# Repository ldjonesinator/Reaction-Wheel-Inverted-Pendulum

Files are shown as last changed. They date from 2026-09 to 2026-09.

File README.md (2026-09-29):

# Reaction Wheel Inverted Pendulum
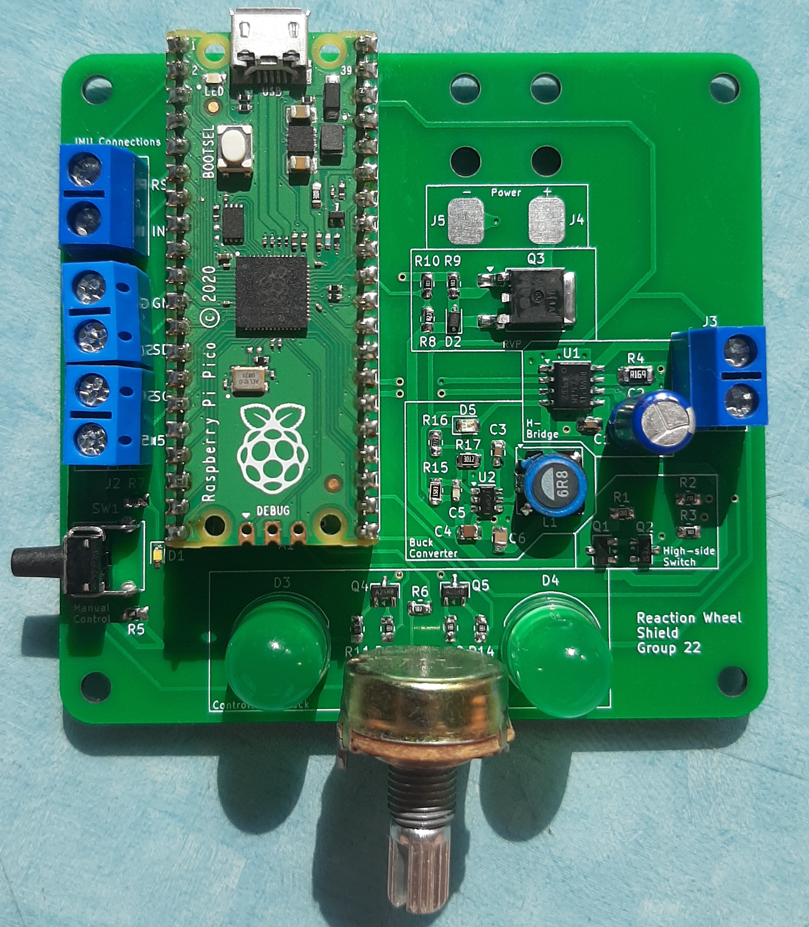
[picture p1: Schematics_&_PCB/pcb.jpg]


## How it works
An inverted pendulum is an inherently unstable mechanical system because its centre of mass is positioned above its pivot point. As a result, small disturbances cause the pendulum to move away from its upright position unless corrected back to its original position. In this project, torque is produced by accelerating or decelerating a reaction wheel mounted to the pendulum. The resulting reaction torque acts on the pendulum body and is used to oppose its movement. 

The design uses an inertial measurement unit (IMU), to measure the pendulum’s angular position and motion. These measurements are processed by a Raspberry Pi Pico, which runs the feedback-control algorithm. The resulting control signal is supplied to an H-bridge motor driver, allowing the speed and direction of the brushed geared DC motor to be controlled. The motor drives the reaction wheel, completing the closed-loop control system. 

## How to use
You can refer to the documentation located in: [Instructions](Instructions.pdf)

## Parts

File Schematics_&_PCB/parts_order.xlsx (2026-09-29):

Component | Link | Part number | Amount | Price (NZD) | Total Price
Buck Switching Regulator IC Positive Adjustable AP63301WU-7 | https://www.digikey.co.nz/en/products/detail/diodes-incorporated/AP63301WU-7/10491607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 | 31-AP63301WU-7CT-ND | 1 | $1.99 | $1.99
H-Bridge DRV8231DDAR | https://www.digikey.co.nz/en/products/detail/texas-instruments/DRV8231DDAR/16184249 | 296-DRV8231DDARCT-ND | 1 | $3.24 | $3.24
Red Banana socket | https://www.digikey.co.nz/en/products/detail/cliff-electronic-components-ltd/FCR7350R/17729035 | 4654-FCR7350R-ND | 0 | $14.04 | $0.00
Black Banana socket | https://www.digikey.co.nz/en/products/detail/cliff-electronic-components-ltd/FCR7350B/17729030 | 4654-FCR7350B-ND | 0 | $14.04 | $0.00
Cyan 2P Screw Terminal TB002-500-02BE | https://www.digikey.co.nz/en/products/detail/same-sky-formerly-cui-devices/TB002-500-02BE/10064069 | 102-6145-ND | 1 | $0.70 | $0.70
Green 2P Screw Terminal 691137710002 | https://www.digikey.co.nz/en/products/detail/w%C3%BCrth-elektronik/691137710002/6644051 | 732-10955-ND | 1 | $0.79 | $0.79
Green 4P Screw Terminal 691137710004 | https://www.digikey.co.nz/en/products/detail/w%C3%BCrth-elektronik/691137710004/6644053 | 732-10957-ND | 1 | $1.52 | $1.52
Green 10mm LED WP813GD | https://www.digikey.co.nz/en/products/detail/kingbright/WP813GD/3084264 | 754-1898-ND | 2 | $0.69 | $1.38
Right angle THT Switch 1-1825027-1 | https://www.digikey.co.nz/en/products/detail/te-connectivity-alcoswitch-switches/1-1825027-1/1632544 | 450-1658-ND | 1 | $0.56 | $0.56
Orange LED 2mA XZCM2MOK54WA-1VF | https://www.digikey.co.nz/en/products/detail/sunled/XZCM2MOK54WA-1VF/15761908 | 1497-XZCM2MOK54WA-1VFCT-ND | 1 | $0.98 | $0.98
White LED 5mA LW Q98G.01-R2T1-3K6L-1-5-R18 | https://www.digikey.co.nz/en/products/detail/ams-osram-ag/LW-Q98G-01-R2T1-3K6L-1-5-R18/21556497 | 475-LWQ98G.01-R2T1-3K6L-1CT-ND | 1 | $0.36 | $0.36
20p Female Connector 61302011821 | https://www.digikey.co.nz/en/products/detail/w%C3%BCrth-elektronik/61302011821/16608603 | 732-61302011821-ND | 2 | $1.83 | $3.66
PMOS 100V 6.6A FQD8P10TM | https://www.digikey.co.nz/en/products/detail/onsemi/FQD8P10TM/1054070 | FQD8P10TMCT-ND | 1 | $2.78 | $2.78
PMOS 30V 4.3A DMP3056L-7 | https://www.digikey.co.nz/en/products/detail/diodes-incorporated/DMP3056L-7/5126843 | DMP3056L-7DICT-ND | 1 | $1.31 | $1.31
NMOS 60 V 265mA NX138BKR | https://www.digikey.co.nz/en/products/detail/nexperia-usa-inc/NX138BKR/5981270 | 1727-2662-1-ND | 1 | $0.36 | $0.36
NMOS 20 V 3A SLMT320V3CN | https://www.digikey.co.nz/en/products/detail/shenzhen-slkormicro-semicon-co-ltd/SLMT320V3CN/29782446 | 5399-SLMT320V3CNCT-ND | 2 | $0.21 | $0.41
DIODE ZENER 24V 300mW MM3Z24VT1G | https://www.digikey.co.nz/en/products/detail/onsemi/MM3Z24VT1G/661665 | MM3Z24VT1GOSCT-ND | 1 | $0.33 | $0.33
47uF Al Electrolytic Capacitor 860010572005 | https://www.digikey.co.nz/en/products/detail/w%C3%BCrth-elektronik/860010572005/5726976 | 732-8735-1-ND | 1 | $0.23 | $0.23
100nF Ceramic Capacitor CL21B104KBCNNNC | https://www.digikey.co.nz/en/products/detail/samsung-electro-mechanics/CL21B104KBCNNNC/3886661 | 1276-1003-1-ND | 2 | $0.21 | $0.41 | low esr checked
10uF Ceramic Capacitor C2012X5R1V106K125AC | https://www.digikey.co.nz/en/products/detail/tdk/C2012X5R1V106K085AC/3956083 | 445-14418-1-ND | 1 | $1.00 | $1.00 | low esr checked
47pF Ceramic Capacitor GCM1885C2A470JA16J | https://www.digikey.co.nz/en/products/detail/murata-electronics/GCM1885C2A470JA16J/2591757 | 490-GCM1885C2A470JA16JCT-ND | 1 | $0.23 | $0.23
47uF Ceramic Capacitor C2012X5R0J476M125AC | https://www.digikey.co.nz/en/products/detail/tdk/C2012X5R0J476M125AC/2443465 | 445-5987-1-ND | 1 | $1.41 | $1.41 | low esr checked
6.8uH Shielded Inductor SLF7045T-6R8M1R7-PF | https://www.digikey.co.nz/en/products/detail/tdk/SLF7045T-6R8M1R7-PF/755381 | 445-2029-1-ND | 1 | $1.62 | $1.62
30.1kΩ Thick Film resistor CR0805-FX-3012ELF | https://www.digikey.co.nz/en/products/detail/bourns-inc/CR0805-FX-3012ELF/3784840 | CR0805-FX-3012ELFCT-ND | 1 | $0.21 | $0.21
158kΩ Thick Film resistor CR0805-FX-1583ELF | https://www.digikey.co.nz/en/products/detail/bourns-inc/CR0805-FX-1583ELF/3784668 | 118-CR0805-FX-1583ELFCT-ND | 1 | $0.21 | $0.21
10k Thick film Resistor RMCF0805FT10K0 | https://www.digikey.co.nz/en/products/detail/stackpole-electronics-inc/RMCF0805FT10K0/1760676 | RMCF0805FT10K0CT-ND | 4 | $0.21 | $0.83
1k Thick film Resistor RNCP0805FTD1K00 | https://www.digikey.co.nz/en/products/detail/stackpole-electronics-inc/RNCP0805FTD1K00/2240229 | RNCP0805FTD1K00CT-ND | 2 | $0.21 | $0.41
0.169Ω 1W Thick film resistor RLC73PD2BR169FTD | https://www.digikey.co.nz/en/products/detail/te-connectivity-passive-product/RLC73PD2BR169FTD/19238107 | 1712-RLC73PD2BR169FTDCT-ND | 1 | $0.83 | $0.83
82k Thick Film resistor CRCW080582K0FKEA | https://www.digikey.co.nz/en/products/detail/vishay-dale/CRCW080582K0FKEA/1175855 | 541-82.0KCCT-ND | 1 | $0.21 | $0.21
100k Thick Film resistor CRCW0805100KFKEA | https://www.digikey.co.nz/en/products/detail/vishay-dale/CRCW0805100KFKEA/1175865 | 541-100KCCT-ND | 1 | $0.21 | $0.21
180 Thick Film resistor RC0805JR-07180RL | https://www.digikey.co.nz/en/products/detail/yageo/RC0805JR-07180RL/728263 | 311-180ARCT-ND | 4 | $0.21 | $0.83
2.7k Thick Film Resistor CRG0805F2K7 | https://www.digikey.co.nz/en/products/detail/te-connectivity-passive-product/CRG0805F2K7/2380883 | A126359CT-ND | 2 | $0.21 | $0.41
10K LINEAR Potentiometer PDB181-B225K-103B | https://www.digikey.co.nz/en/products/detail/bourns-inc/PDB181-B225K-103B/6153329 | PDB181-B225K-103B | 1 | $2.68 | $2.68
 |  |  |  | TOTAL | $32.11

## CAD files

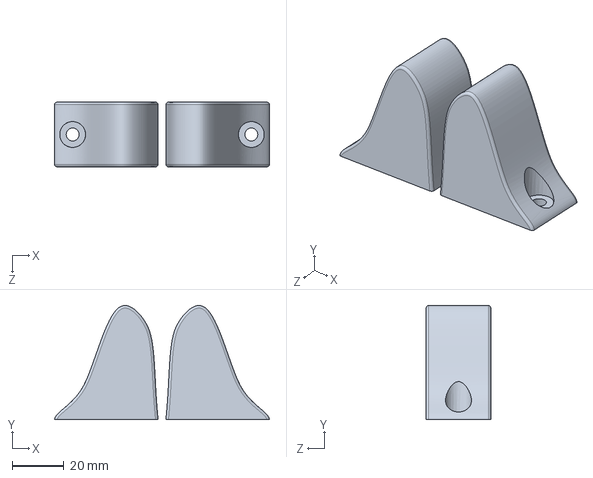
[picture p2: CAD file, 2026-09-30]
CAD/print/armholders1.2.SLDASM
83.0 x 44.0 x 25.0 mm
armholder1.2 x 2

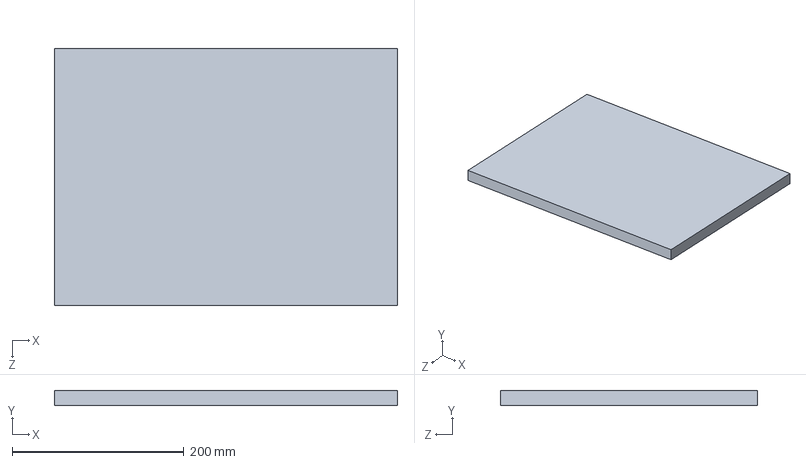
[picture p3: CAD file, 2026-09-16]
CAD/pendulum1.0/non_printed/base.SLDPRT
400.0 x 18.0 x 300.0 mm

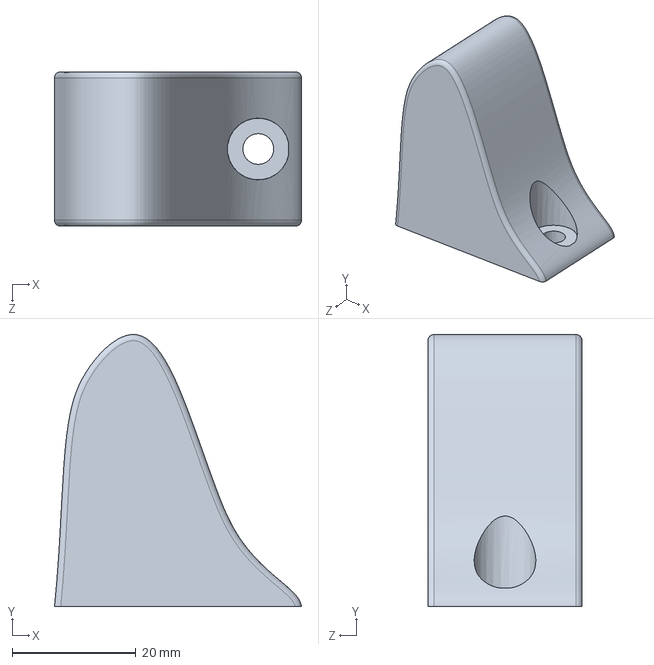
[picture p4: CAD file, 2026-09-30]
CAD/pendulum1.2/armholder1.2.SLDPRT
40.0 x 44.0 x 25.0 mm

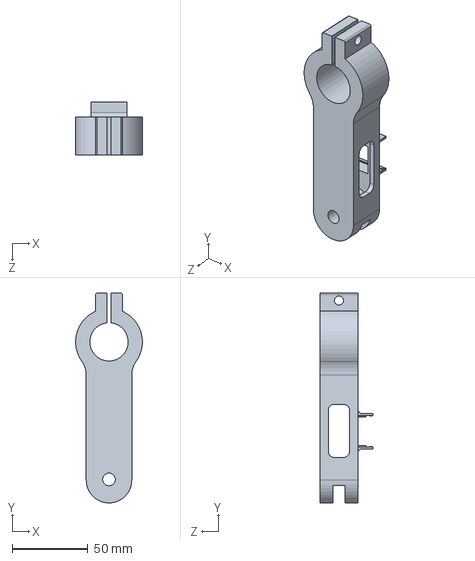
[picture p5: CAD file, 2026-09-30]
CAD/pendulum1.3/arm1.3.SLDPRT
43.9 x 138.3 x 35.0 mm

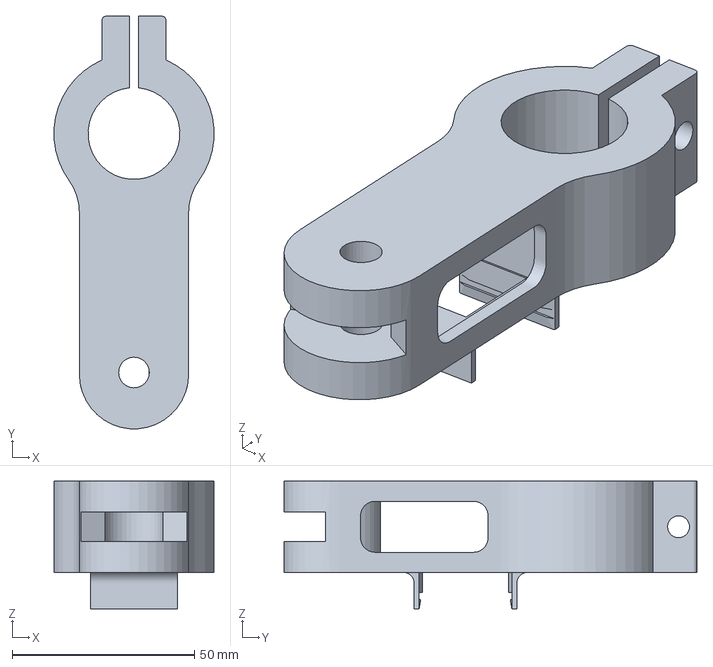
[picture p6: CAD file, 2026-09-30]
CAD/print/arm1.2.3MF
43.9 x 113.2 x 35.0 mm

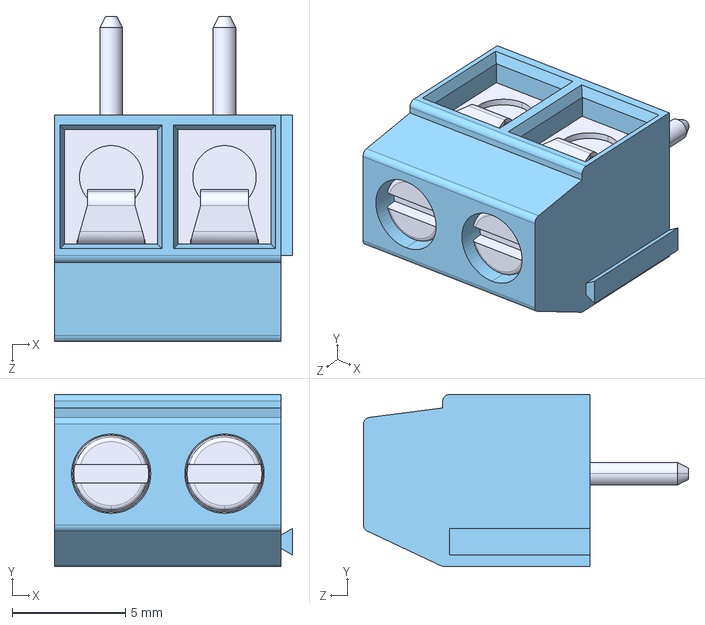
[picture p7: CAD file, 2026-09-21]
Schematics_&_PCB/inverted_pendulum_shield/Same_Sky_TB002-500-02BE.step
10.5 x 7.60 x 14.4 mm

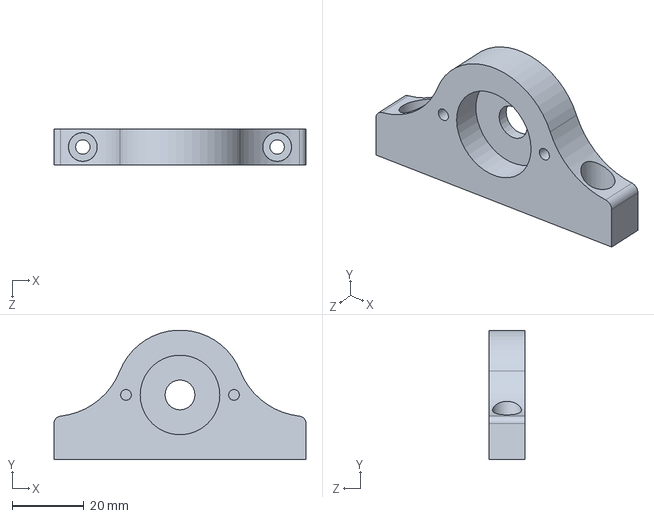
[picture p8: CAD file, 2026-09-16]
CAD/pendulum1.0/hinge.SLDPRT
70.0 x 36.0 x 10.0 mm

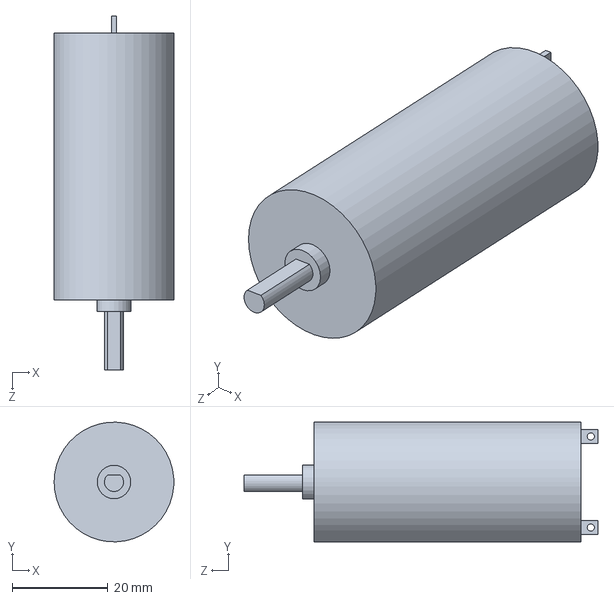
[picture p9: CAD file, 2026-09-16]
CAD/pendulum1.0/non_printed/motor.SLDPRT
25.0 x 25.0 x 73.9 mm

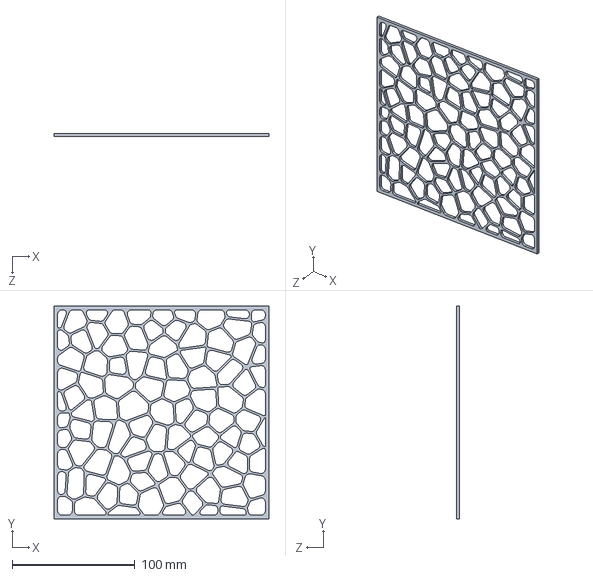
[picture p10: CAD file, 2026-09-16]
CAD/pendulum1.1/voronoi.SLDPRT
174.9 x 173.1 x 2.50 mm

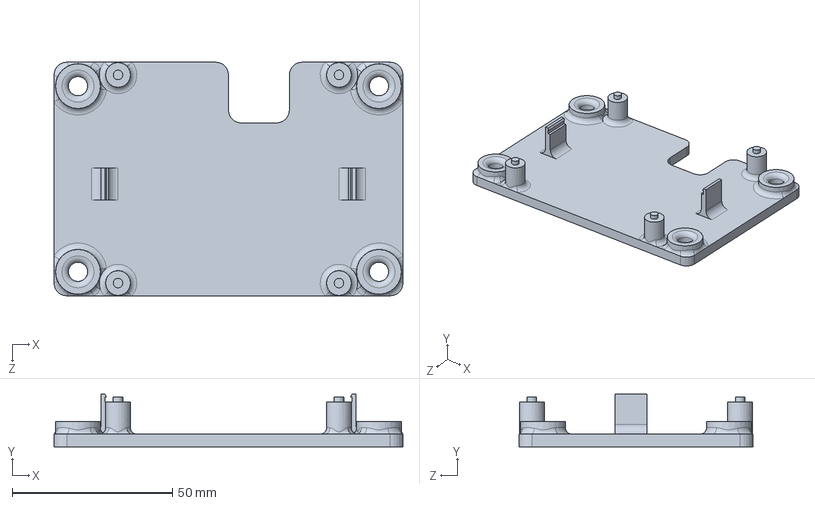
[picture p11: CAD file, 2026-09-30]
CAD/pendulum1.2/pcbholder1.2.SLDPRT
109.0 x 16.5 x 73.0 mm

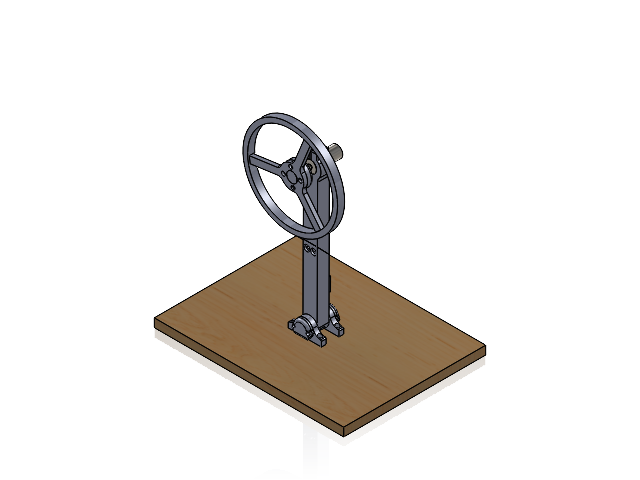
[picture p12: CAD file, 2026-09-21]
CAD/pendulum1.0/pendulum1.0.SLDASM
hinge x 2
wheel
wheeladapter
bearingcover x 2

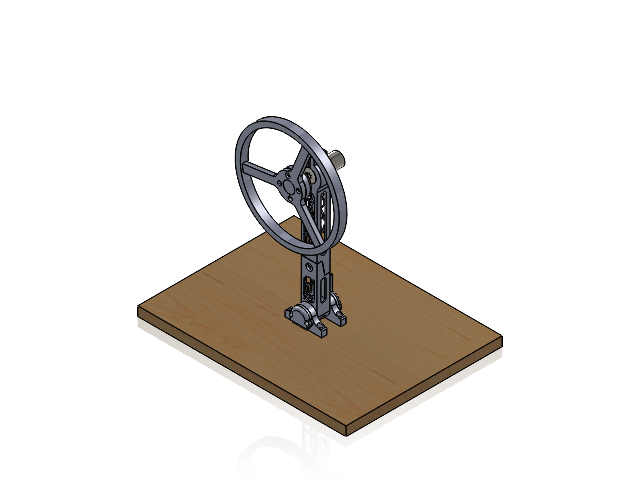
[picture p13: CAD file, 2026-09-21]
CAD/pendulum1.1/pendulum1.1.SLDASM
base
bearing x 2
bottomarm1.1
clamphub
hinge x 2
motor
shaft
shaftcollar
toparm1.1
washer x 2
wheel
wheeladapter
bearingcover x 2
imu

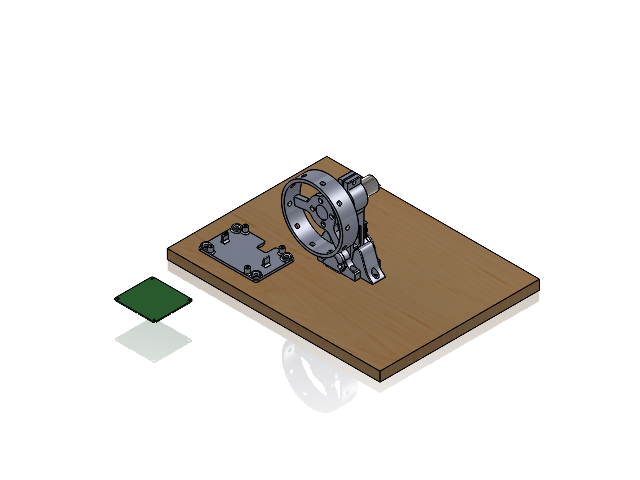
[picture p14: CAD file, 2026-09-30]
CAD/pendulum1.2/pendulum1.2.SLDASM
base
bearing x 2
arm1.3
clamphub
hinge x 2
motor
shaft
wheel1.2
wheeladapter
bearingcover x 2
imu
armholder1.2 x 2
pcbholder1.2
pcb1.2

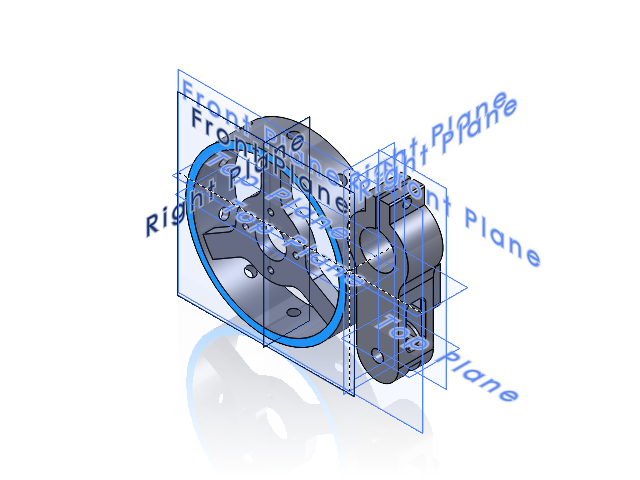
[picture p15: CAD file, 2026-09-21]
CAD/print/pendulum1.2print.SLDASM
arm1.2
wheel1.2

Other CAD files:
CAD/print/testprint.SLDASM
CAD/print/arms1.1.SLDASM
CAD/print/wheelandparts1.1.SLDASM
CAD/print/hubhinge.SLDASM
CAD/pendulum1.0/bearingcover.SLDPRT
CAD/pendulum1.0/non_printed/bearing.SLDPRT
CAD/pendulum1.0/non_printed/clamphub.SLDPRT
CAD/pendulum1.0/non_printed/imu.SLDPRT
CAD/pendulum1.0/non_printed/shaft.SLDPRT
CAD/pendulum1.0/non_printed/shaftcollar.SLDPRT
CAD/pendulum1.0/non_printed/washer.SLDPRT
CAD/pendulum1.0/wheel.SLDPRT
CAD/pendulum1.0/wheeladapter.SLDPRT
CAD/pendulum1.1/wheel1.1.SLDPRT
CAD/pendulum1.2/arm1.2.SLDPRT
CAD/pendulum1.2/pcb1.2.SLDPRT
CAD/pendulum1.2/wheel1.2.SLDPRT
CAD/print/arm1.3.3MF
CAD/print/armholders1.2.3MF
CAD/print/arms2.0.3MF
CAD/print/bearingcovers.3MF
CAD/print/hubhinge.3MF
CAD/print/pcbholder1.2.3MF
CAD/print/pendulum1.1.3MF
CAD/print/pendulum1.2.3MF
CAD/print/wheel.3MF
CAD/print/wheel1.1.3MF
CAD/print/wheelandparts1.1.3MF
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

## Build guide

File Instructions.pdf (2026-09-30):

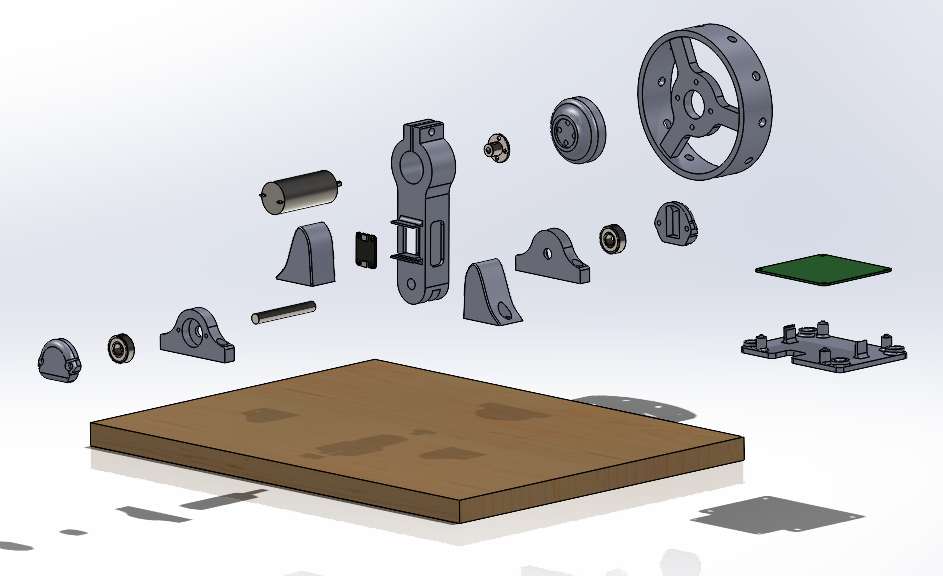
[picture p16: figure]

1

# Inverted Pendulum Reaction Wheel Instructions:

# Pendulum Setup

(There are fasteners and wires missing from this image. This includes: 12x M3 screws, connectors for the motor and imu, 10x mber screws for base mounng and a bolt and nut set for the motor mount)

### Tools needed: Phillips screwdriver, ny phillips screwdriver, M3 allen key

### 30 September 2026

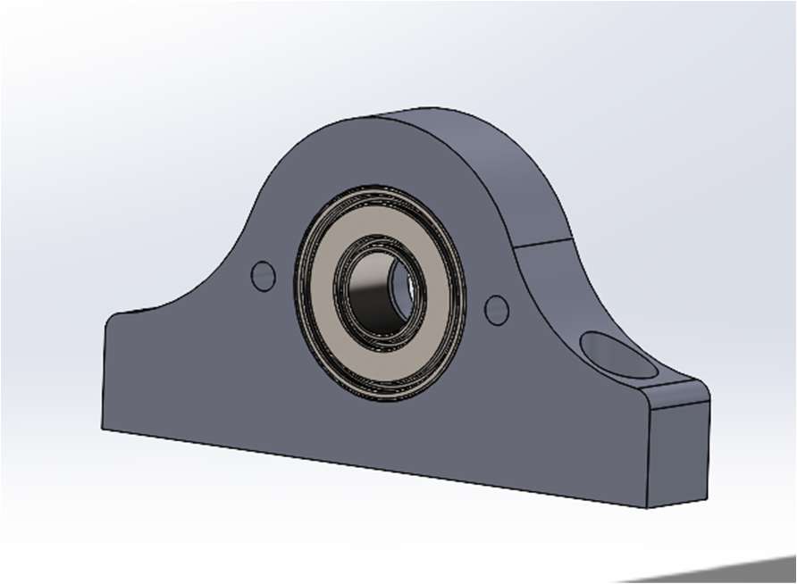
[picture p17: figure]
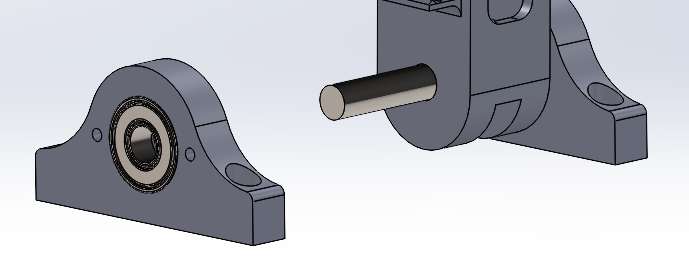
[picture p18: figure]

2

### 1. Hinge and Bearing

Insert one bearing into each of the two bearing housings on the base.
The bearings should be seated flush inside the hinge.
Do not force the bearings into posion at an angle.

### 2. Sha

Slide the sha through the first bearing, pendulum arm and into the second bearing.
Ensure the sha passes freely through both bearings.
The arm should rotate smoothly without significant resistance.

### 3. Hinge mount

Posion the two hinges on the base board according to the specified hole locaons. The rough and exposed wood edge of the board should be facing away and at the back.
Secure each hinge to the board using four mber screws, ghtening them evenly to ensure the hinges remain straight and aligned.
Check that both hinges are parallel to each other before fully ghten.
It is very important to prevent any fricon from keeping the pendulum from moving freely.

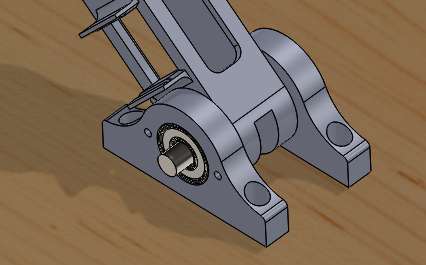
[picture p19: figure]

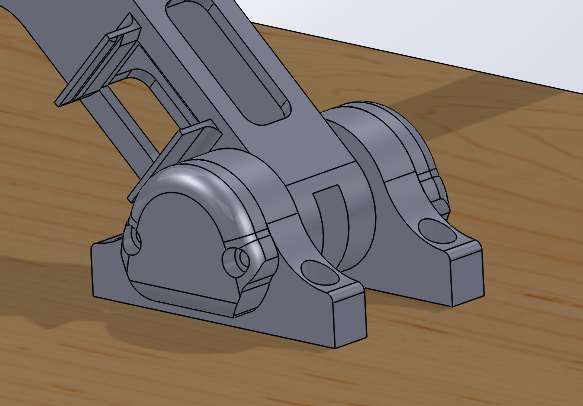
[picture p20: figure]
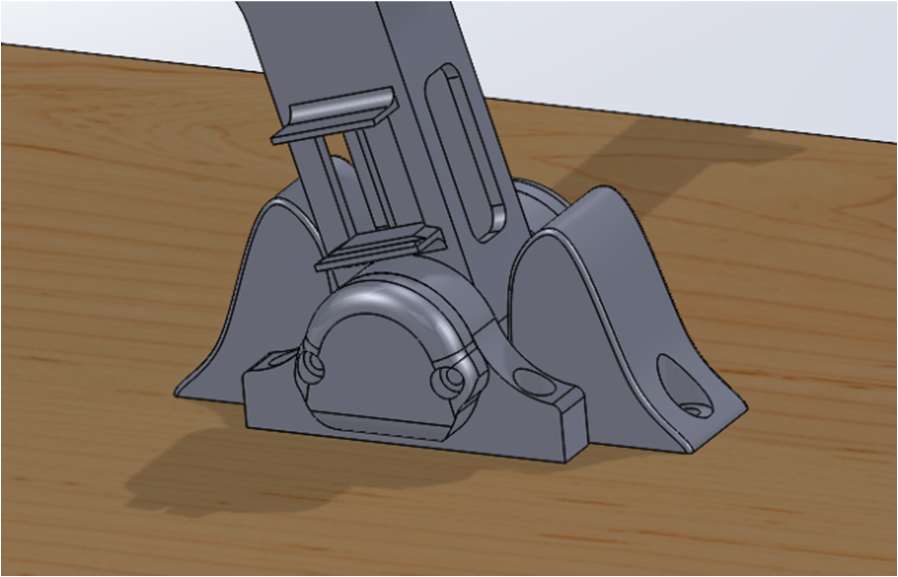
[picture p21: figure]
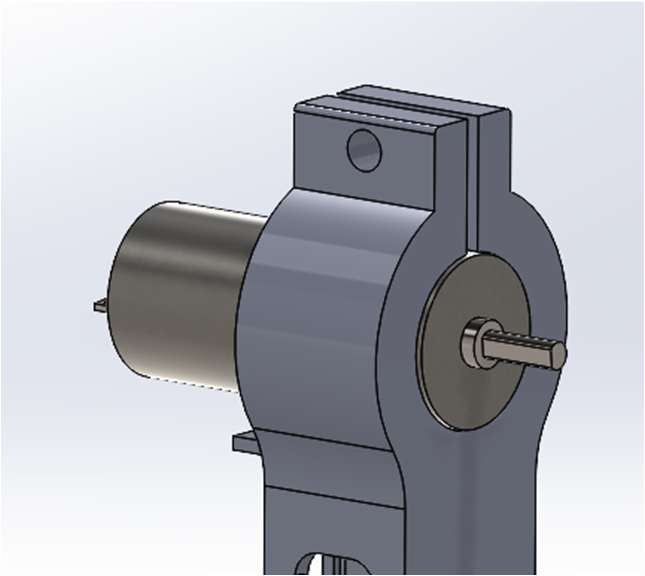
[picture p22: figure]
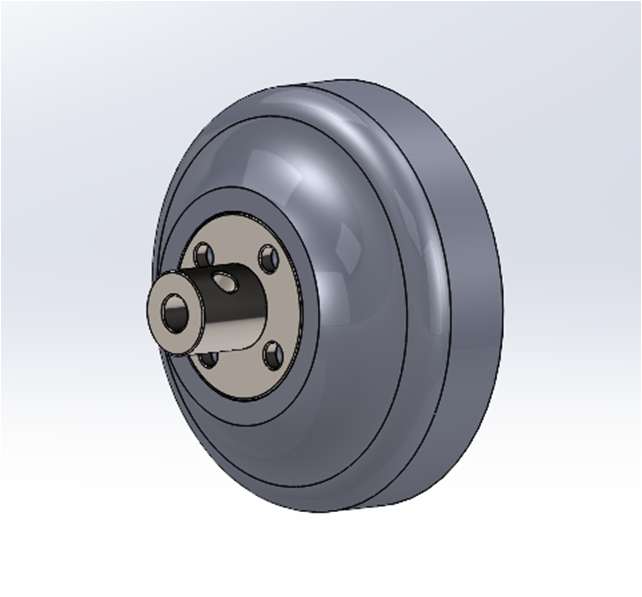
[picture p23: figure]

3

### 4. Sha Covers

Place the bearing and sha covers over the bearings and sha ends on both sides of the base. Secure the covers using M3 screws, ensuring they sit flush against the hinges.
Check that the covers do not interfere with the sha or restrict its rotaon.

### 5. Arm Supports

Posion the two arm supports on the base board according to the specified hole locaons. Use the closest holes to the arm for now. The other holes can be used if the starng angle needs to be changed.
Secure each arm support to the board using two mber screws.

### 6. Motor

Place the motor into the motor mount integrated into the pendulum arm.
Ensure the motor is fully seated in the mounng feature and that the motor face is flush with the arm as shown.
Secure the motor using the nut and bolt.

### 7. Wheel Adapter

Aach the wheel adapter to the clamp hub using 4x M3 screws. Tighten the four screws progressively in a cross paern to keep the wheel evenly secured to the hub.

### 8. Clamp Hub

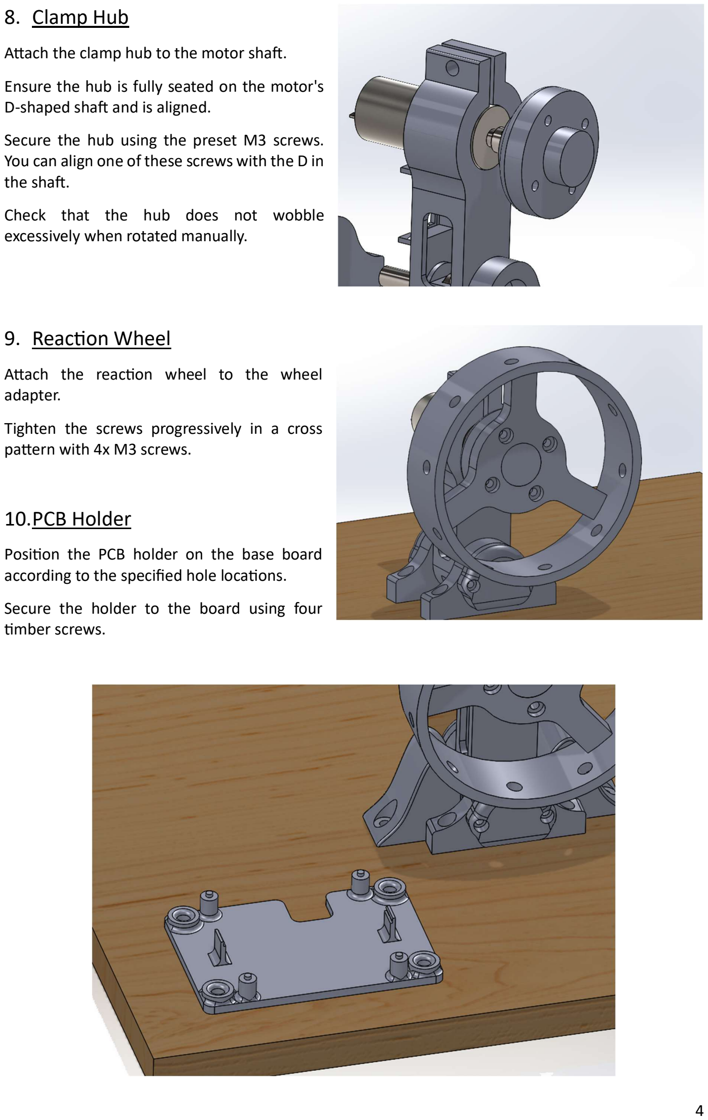
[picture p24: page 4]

4

Aach the clamp hub to the motor sha. Ensure the hub is fully seated on the motor's D-shaped sha and is aligned.
Secure the hub using the preset M3 screws. You can align one of these screws with the D in the sha.
Check that the hub does not wobble excessively when rotated manually.

### 9. Reacon Wheel

Aach the reacon wheel to the wheel adapter.
Tighten the screws progressively in a cross paern with 4x M3 screws.

### 10.PCB Holder

Posion the PCB holder on the base board according to the specified hole locaons. Secure the holder to the board using four mber screws.

### 11.IMU

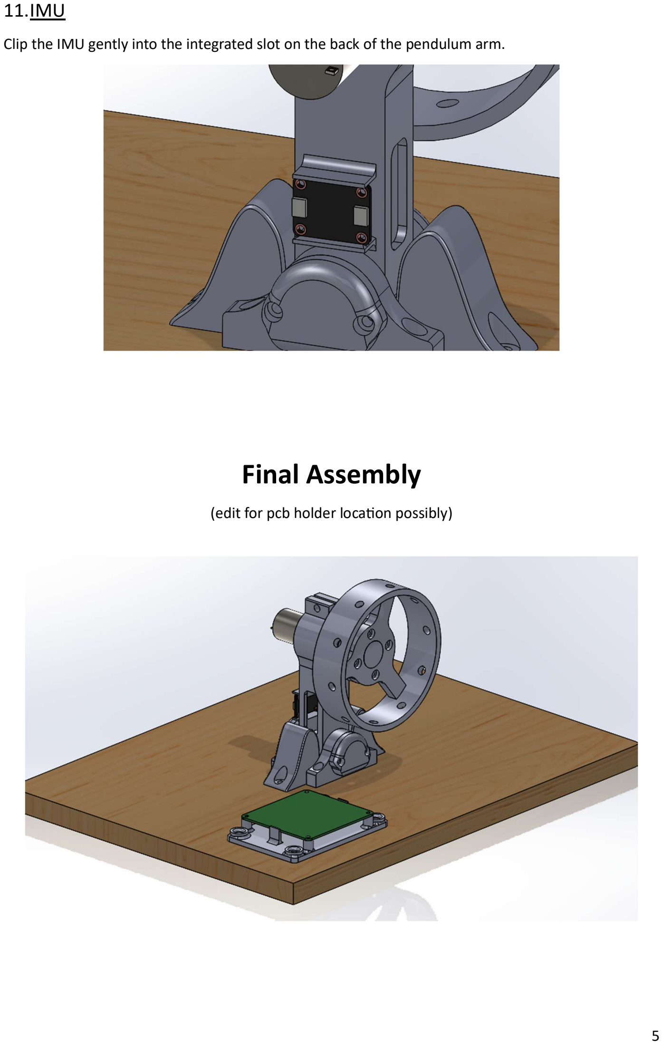
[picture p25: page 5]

5

Clip the IMU gently into the integrated slot on the back of the pendulum arm.

# Final Assembly

(edit for pcb holder locaon possibly)

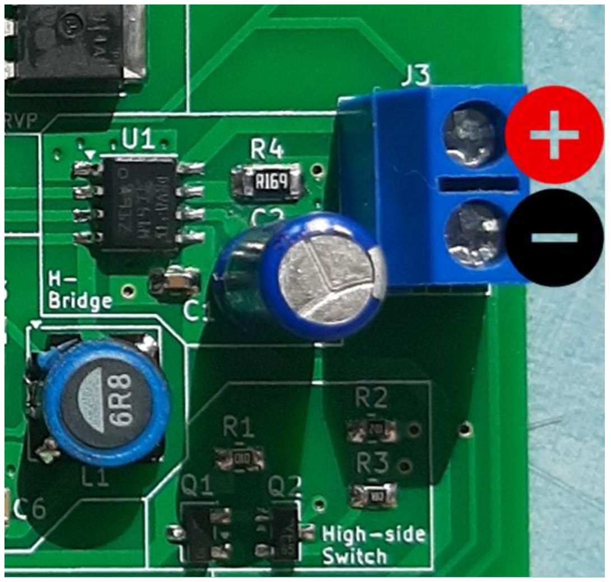
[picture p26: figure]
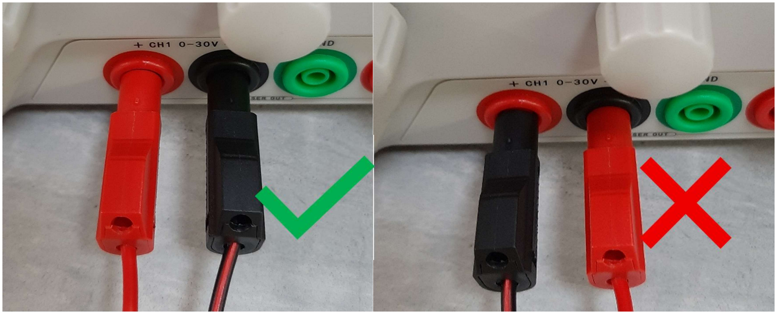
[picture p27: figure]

6

# Board Setup

## Wiring

Before you power on the board, you must ensure the motor and IMU are connected to the blue screw terminals located on either side of the board. The IMU has 4 connecons located on the le of the board while the motor has two. The IMU also has 2 oponal connecons labelled RST and INT that aren’t necessary. Following the silkscreen prinng on the PCB and IMU to connect them together properly. The red wire on the motor should be connected to the top screw terminal and the black on the boom. This can be seen in the reference photo to the right.
Once this is done you are ready to power on the board.

## Power

For power the board can use a bench power supply which you can connect with the banana cables that the board has. It is important that the board is connected the right way otherwise the board will not funcon. Make sure you connect the red cable to the posive terminal of your power supply, and the black cable to the negave end. See the photos below:

Make sure the supply is set to 12V and be sure to keep the current limit at around 3 Amps. Once the system is on there will be an orange light that will turn on to indicate that the Raspberry Pi Pico has power. If the board has an input voltage of 12V, then the motor will begin spinning.

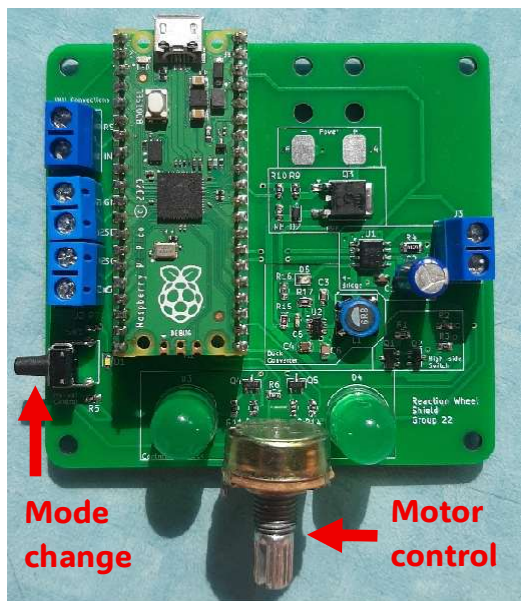
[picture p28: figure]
Mode change; Motor control

7

# Board Controls

Once the board has power, there are a couple controls. First is the “mode change” switch which will toggle between manual mode and controls mode. This is located on the boom le of the board as seen in the reference image. Controls mode is the default mode where the board will use a control loop to keep the pendulum upright. Manual mode turns off this loop and requires the user to use the dial (located at the boom of the PCB) to keep the pendulum upright. The farther the dial is turned in one direcon, the faster the motor spins.

# Recalibration

If the Raspberry Pi Pico needs to be replaced or recalibrated with the code, it can be connected to the board with a USB plug. Please note that the board cannot be powered with this alone, but will not be damaged when this occurs. Please be sure keep the PCB unplugged from the power supply when doing this as to not damage the system. Once the code has been uploaded to the Pico, make sure to unplug the USB cable before operang.

# Safey systems:

The PCB has a couple safety features in case of improper use of the system. It has reverse polarity protecon in case the input voltage is connected the way around. It also has some overvoltage protecon up to 30V. Any higher and the PCB will be damaged.
The PCB holder will be mounted onto the board to display the PCB safely. The PCB clips onto the holder through two clips in addion to four divots to keep the PCB in posion. This also ensures that the PCB will not be accidentally bumped or yanked off the board.
Arm holders are screwed into the board to keep the pendulum arm from falling. This will also keep the wheel safe and prevent the wheel from rubbing against the board. The code also includes a safe guard on top of this, liming the angle that the pendulum will try to correct. Once the pendulum exceeds this angle, the motor will stop spinning.

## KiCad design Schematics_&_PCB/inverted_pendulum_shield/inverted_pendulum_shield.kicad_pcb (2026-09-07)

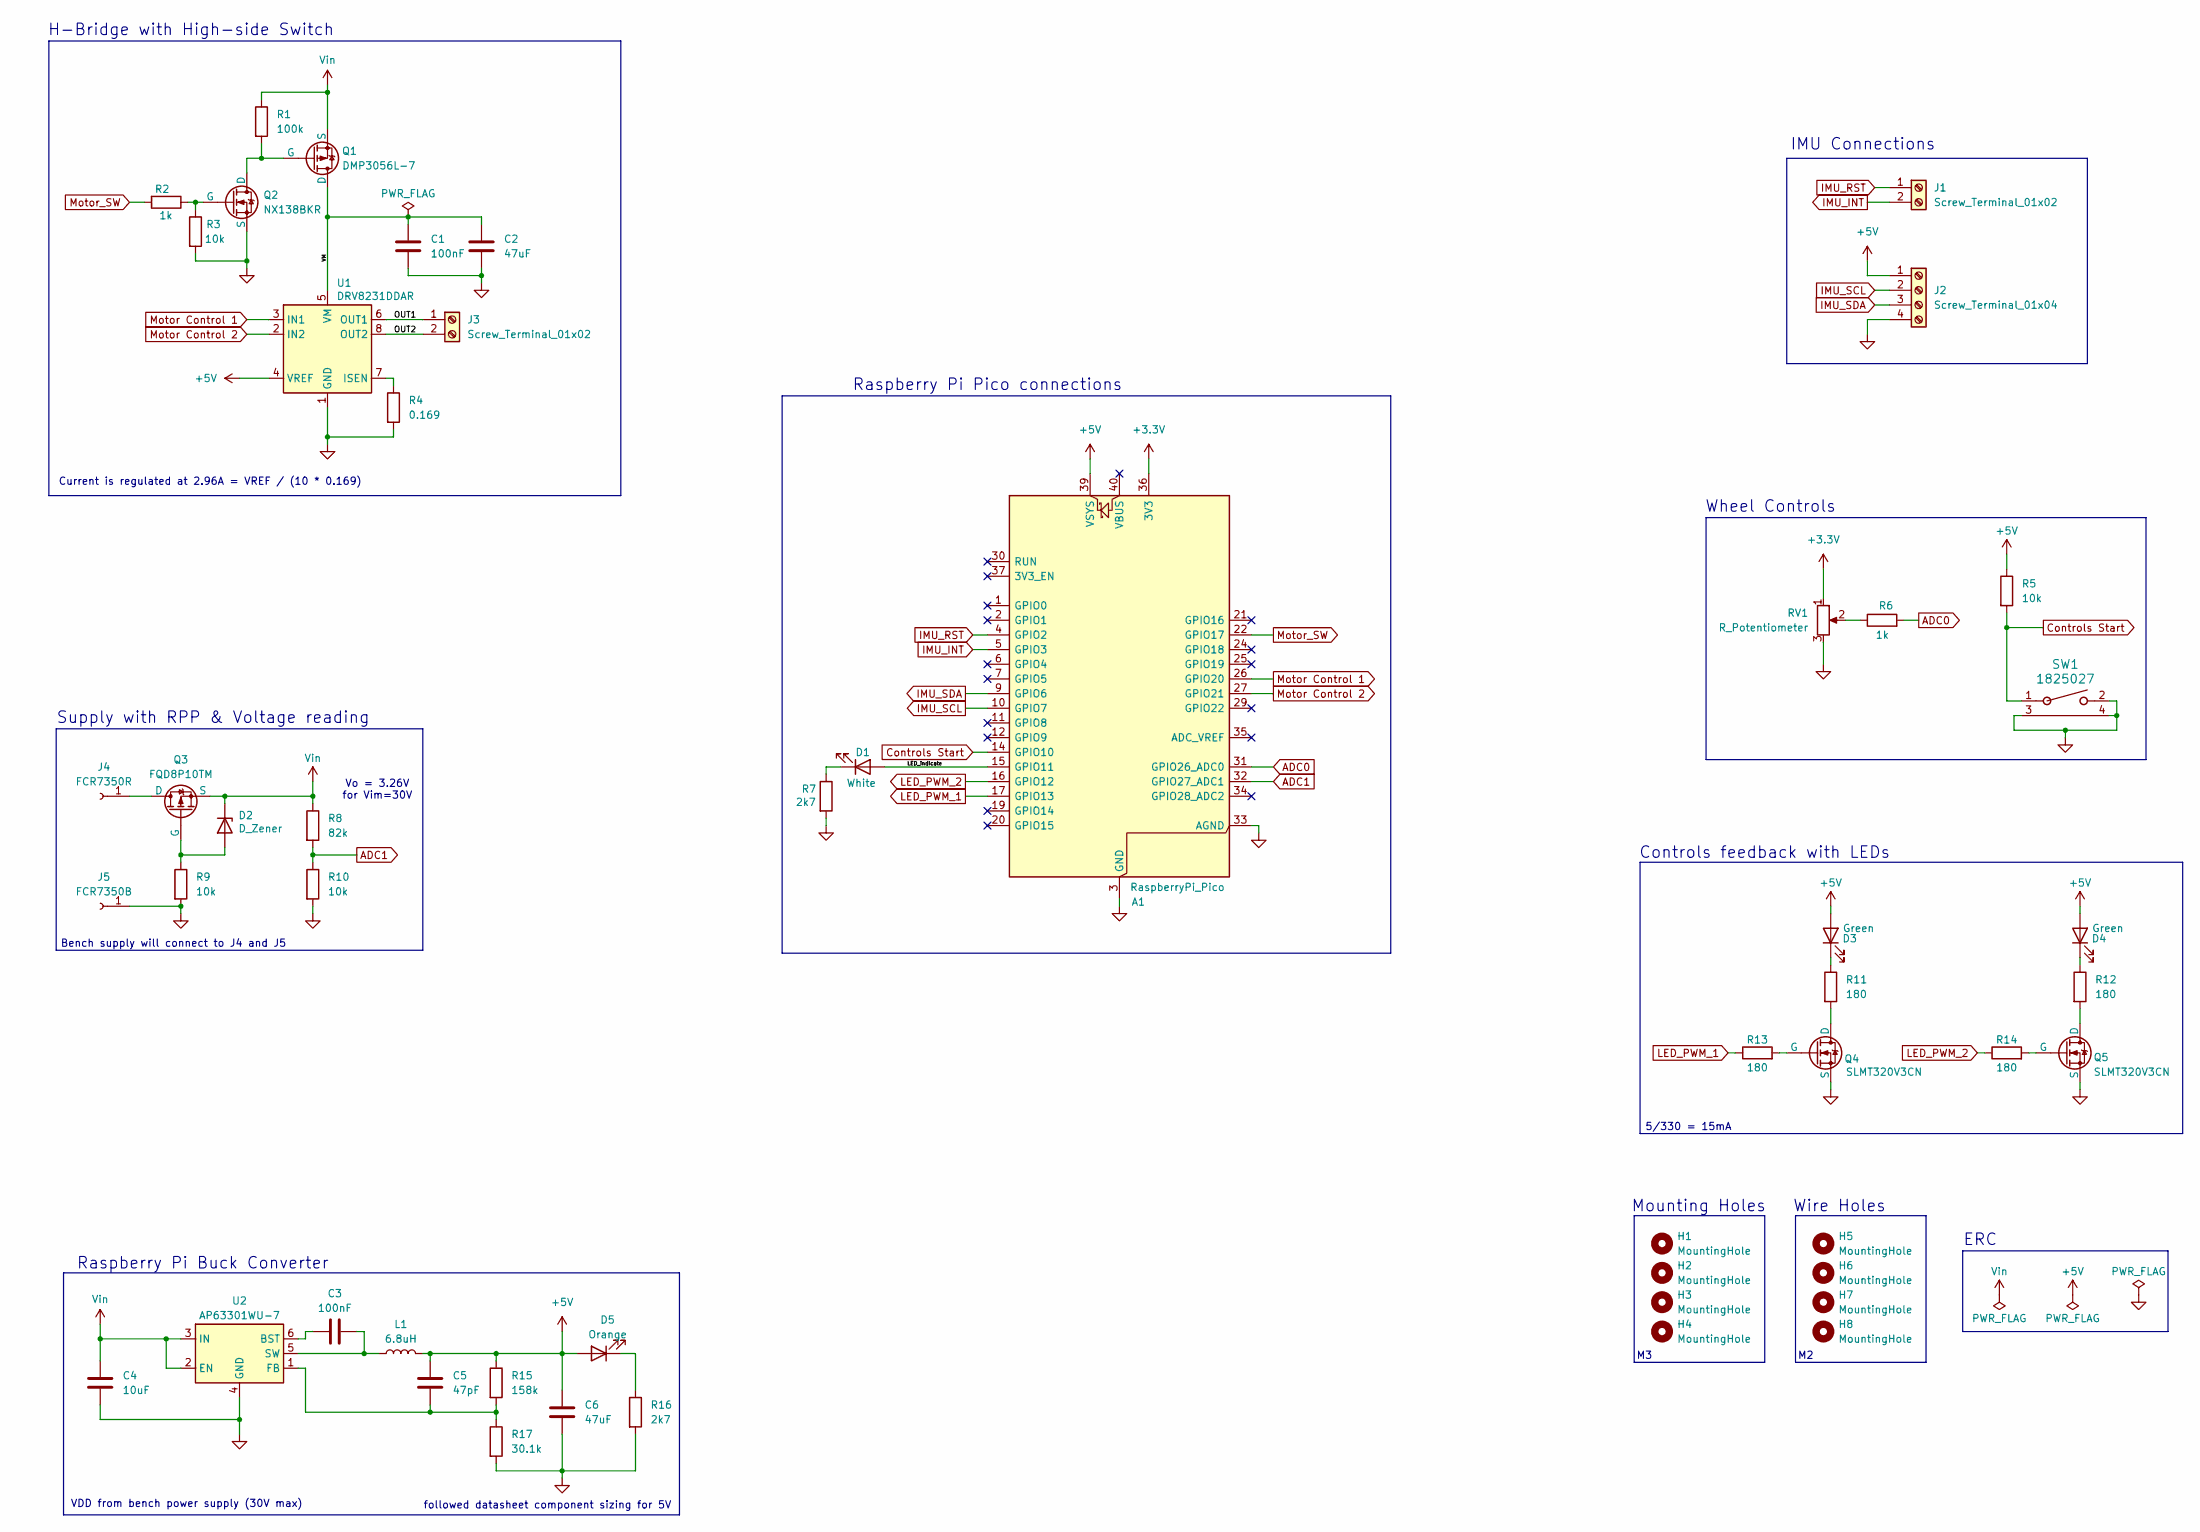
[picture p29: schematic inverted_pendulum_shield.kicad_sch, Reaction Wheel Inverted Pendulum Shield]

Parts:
A1: RaspberryPi_Pico; RaspberryPi_Pico_Common_THT
C1, C3: 100nF; C_0805_2012Metric
C2: 47uF; C_Radial_D5.0mm_H11.0mm_P2.00mm
C4: 10uF; C_0805_2012Metric
C5: 47pF; C_0603_1608Metric
C6: 47uF; C_0805_2012Metric
D1: White; LED_0603_1608Metric
D2: D_Zener; D_SOD-323
D3, D4: Green; LED_D10.0mm
D5: Orange; LED_0805_2012Metric
H1, H2, H3, H4, H5, H6, H7, H8: MountingHole; MountingHole_3.2mm_M3
J1, J3: Screw_Terminal_01x02; TerminalBlock_MaiXu_MX126-5.0-02P_1x02_P5.00mm
J2: Screw_Terminal_01x04; TerminalBlock_MaiXu_MX126-5.0-04P_1x04_P5.00mm
J4: FCR7350R; SolderWirePad_1x01_SMD_4x8mm
J5: FCR7350B; SolderWirePad_1x01_SMD_4x8mm
L1: 6.8uH; L_TDK_SLF7045
Q1: DMP3056L-7; SOT-23-3
Q2: NX138BKR; SOT-23
Q3: FQD8P10TM; TO-252-2
Q4, Q5: SLMT320V3CN; SOT-23
R1: 100k; R_0805_2012Metric
R2, R6: 1k; R_0805_2012Metric
R3, R5, R9, R10: 10k; R_0805_2012Metric
R4: 0.169; R_1206_3216Metric
R7, R16: 2k7; R_0805_2012Metric
R8: 82k; R_0805_2012Metric
R11, R12, R13, R14: 180; R_0805_2012Metric
R15: 158k; R_0805_2012Metric
R17: 30.1k; R_0805_2012Metric
RV1: R_Potentiometer; uc_potentiometer
SW1: 1825027; SW_THT_1825027-G_TEC
U1: DRV8231DDAR; Texas_HTSOP-8-1EP_3.9x4.9mm_P1.27mm_EP2.95x4.9mm_Mask2.4x3.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
U2: AP63301WU-7; TSOT-23-6

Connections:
+3.3V: A1.36 (3V3), RV1.1
+5V: A1.39 (VSYS), C5.1, C6.1, D3.2 (A), D4.2 (A), D5.2 (A), J2.1, L1.2, R5.1, R15.1, U1.4 (VREF)
/LED_indicate: A1.15 (GPIO11), D1.2 (A)
/OUT1: J3.1, U1.6 (OUT1)
/OUT2: J3.2, U1.8 (OUT2)
/VM: C1.1, C2.1, Q1.1 (D), U1.5 (VM)
ADC0: A1.31 (GPIO26_ADC0), R6.2
ADC1: A1.32 (GPIO27_ADC1), R8.2, R10.1
Controls Start: A1.14 (GPIO10), R5.2, SW1.1
GND: A1.3 (GND), A1.8 (GND), A1.13 (GND), A1.18 (GND), A1.23 (GND), A1.28 (GND), A1.33 (AGND), A1.38 (GND), C1.2, C2.2, C4.2, C6.2, J2.4, J5.1 (Pin_1_1), Q2.3 (S), Q4.3 (S), Q5.3 (S), R3.2, R4.2, R7.2, R9.2, R10.2, R16.2, R17.2, RV1.3, SW1.2, SW1.3, SW1.4, U1.1 (GND), U1.9 (GND), U2.4 (GND)
IMU_INT: A1.5 (GPIO3), J1.2
IMU_RST: A1.4 (GPIO2), J1.1
IMU_SCL: A1.10 (GPIO7), J2.2
IMU_SDA: A1.9 (GPIO6), J2.3
LED_PWM_1: A1.17 (GPIO13), R13.1
LED_PWM_2: A1.16 (GPIO12), R14.1
Motor Control 1: A1.26 (GPIO20), U1.3 (IN1)
Motor Control 2: A1.27 (GPIO21), U1.2 (IN2)
Motor_SW: A1.22 (GPIO17), R2.2
unnamed: D1.1 (K), R7.1
unnamed: D2.2 (A), Q3.2 (G), R9.1
unnamed: D3.1 (K), R11.1
unnamed: D4.1 (K), R12.1
unnamed: D5.1 (K), R16.1
unnamed: J4.1 (Pin_1_1), Q3.1 (D)
unnamed: Q1.2 (G), Q2.1 (D), R1.2
unnamed: Q2.2 (G), R2.1, R3.1
unnamed: Q4.1 (D), R11.2
unnamed: Q4.2 (G), R13.2
unnamed: Q5.1 (D), R12.2
unnamed: Q5.2 (G), R14.2
unnamed: R6.1, RV1.2
unnamed: R4.1, U1.7 (ISEN)
unnamed: C3.2, U2.6 (BST)
unnamed: C5.2, R15.2, R17.1, U2.1 (FB)
unnamed: C3.1, L1.1, U2.5 (SW)
Vin: C4.1, D2.1 (K), Q1.3 (S), Q3.3 (S), R1.1, R8.1, U2.2 (EN), U2.3 (IN)

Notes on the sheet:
Supply with RPP & Voltage reading
5/330 = 15mA
Current is regulated at 2.96A = VREF / (10 * 0.169)
followed datasheet component sizing for 5V
Wheel Controls
IMU Connections
H-Bridge with High-side Switch
Wire Holes
Controls feedback with LEDs
Raspberry Pi Buck Converter
Bench supply will connect to J4 and J5
Mounting Holes
ERC
Raspberry Pi Pico connections
Vo = 3.26V for Vim=30V
VDD from bench power supply (30V max)

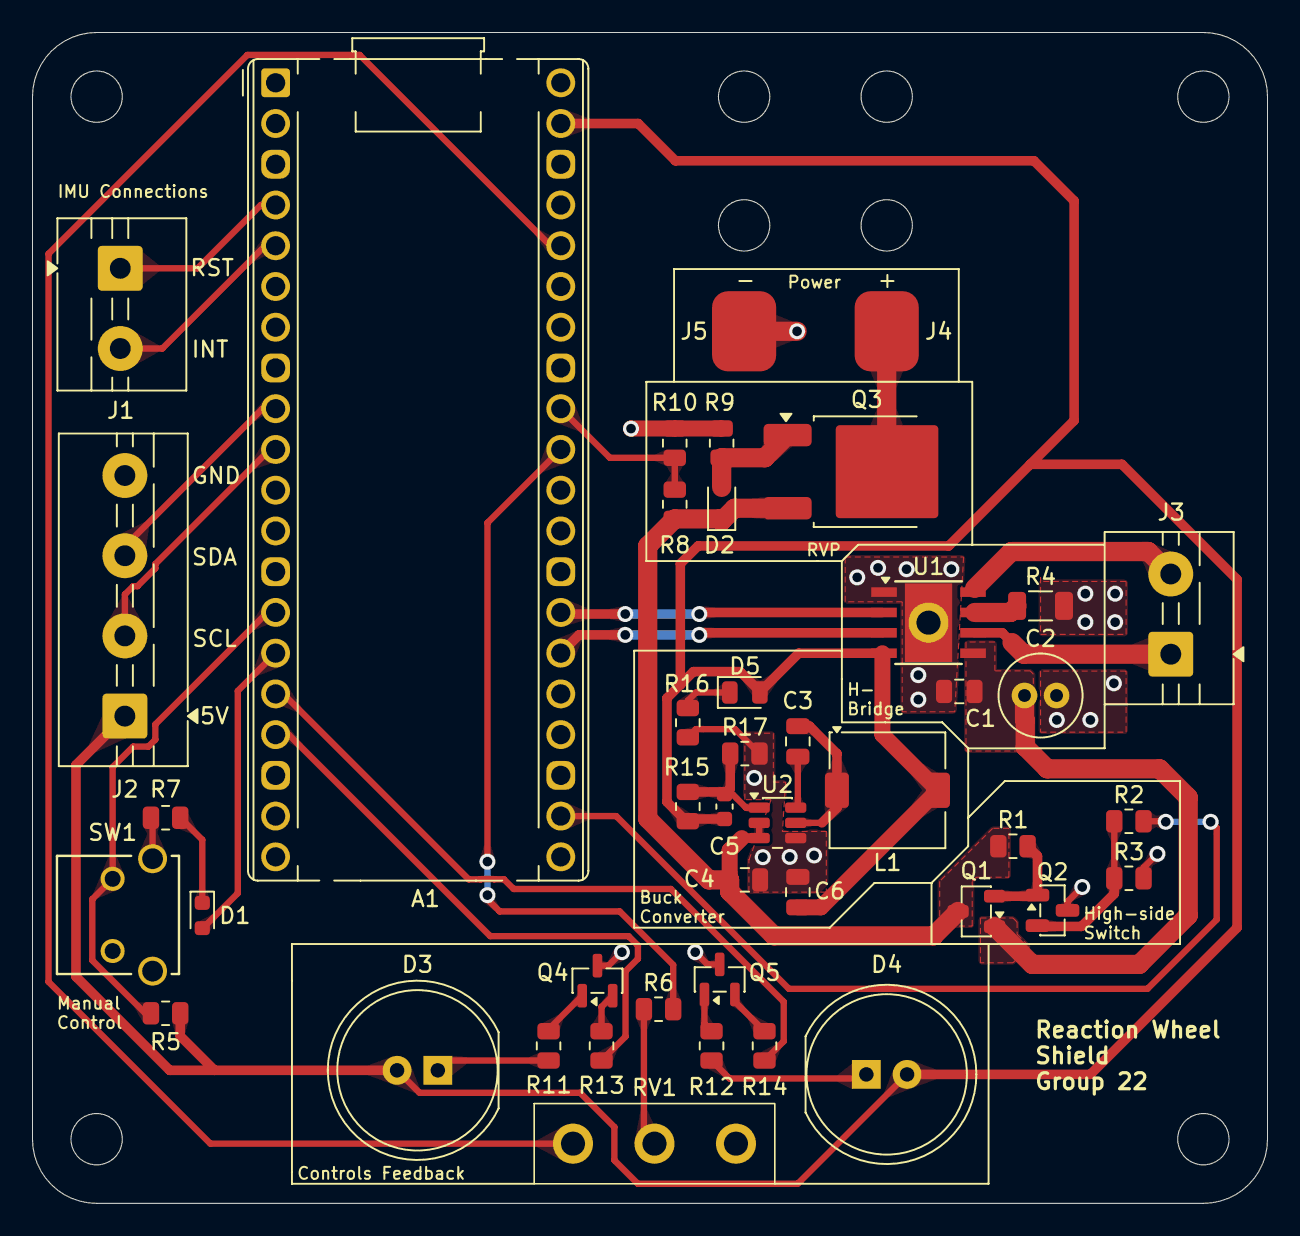
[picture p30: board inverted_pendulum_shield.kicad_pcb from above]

Board: 2 copper layers, 77.0 x 73.0 mm, 52 parts (0 on the bottom side), 37 nets.

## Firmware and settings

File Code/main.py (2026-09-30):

import time

import gpio
from gpio import PIN_RES
import imu_control as imu

import motor_control as motor
import button_control as btn
import pot_control as pot
from pot_control import POT_GAIN

# Third Euler value when the arm is exactly upright.
REF_ANGLE = 0


LOOP_TIME = 0.02
ANGLE_LIMIT = 90.0


KP = 20.0 #NOT 2
KI = 0.0 # must be > 1
KD = 0.0


# The integral term can never contribute more than this many percent
# (anti-windup).
INTEGRAL_LIMIT = 100.0

# Derivative low-pass filter: 1.0 = raw derivative, smaller = smoother.
# The BNO055 angle is quantised to 1/16 degree, so raw derivatives are
# noisy.
DERIV_FILTER = 0.15

# No motor output while the error is inside this many degrees.
ANGLE_DEAD_BAND = 0.10

# ----- Target-angle dithering (Brick's ANGLE_FIXRATE) -------------
# Each loop the target angle is nudged away from the measured angle,
# which keeps the error (and so the wheel acceleration) from settling at
# zero. Brick uses 1.0 deg/s. Leave at 0.0 (off) until P and D work.
ANGLE_FIXRATE = 0.0
# The target can never move further than this from upright (degrees).
TARGET_LIMIT = 10.0

MIN_PWM = 0.0
MAX_PWM = 100.0

# True:  a 0-100% command is stretched over MIN_PWM..MAX_PWM, so small
#        commands give small (but moving) output.
# False: old behaviour - anything below MIN_PWM is lifted to MIN_PWM.
DEADZONE_REMAP = True

REVERSE_MOTOR = False
PWM_FREQUENCY = 20000


USER_MODES = {"MANUAL": 0, "PID": 1}

mode_btn = btn.Button()
user_pot = pot.Pot() # XD


def input_volt_check(was_motor_on):
    # turn on HSS if wasn't on already, vice versa
    if gpio.is_vin_correct() and not was_motor_on:
        motor.turn_on(True)
        return True
    elif not gpio.is_vin_correct() and was_motor_on:
        motor.turn_on(False)
        return False

    return was_motor_on

def clamp(value, minimum, maximum):
    return max(minimum, min(maximum, value))

def wrap_angle(angle):
    """Wrap an angle difference into -180...+180 degrees."""
    return (angle + 180.0) % 360.0 - 180.0


def set_clamped_motor_speed(command):

    command = clamp(command, -100.0, 100.0)
    magnitude = abs(command)

    if magnitude < 0.5:
        motor.stop()
        return 0.0

    if DEADZONE_REMAP:
        duty_percent = MIN_PWM + (MAX_PWM - MIN_PWM) * magnitude / 100.0
    else:
        duty_percent = clamp(magnitude, MIN_PWM, MAX_PWM)

    if command < 0:
        duty_percent = -duty_percent

    motor.set_speed(duty_percent)    
    return duty_percent


def update_direction_leds(command):
    brightness = abs(command)

    if command > 0:
        gpio.set_control_led_brightness(1, brightness)
        gpio.set_control_led_brightness(2, 0)

    elif command < 0:
        gpio.set_control_led_brightness(1, 0)
        gpio.set_control_led_brightness(2, brightness)

    else:
        gpio.set_control_led_brightness(1, 0)
        gpio.set_control_led_brightness(2, 0)


motor_running = False
prev_speed = 0
pot_gain = 5
pin_res = 65535      
speed_ramp_down = 1.0     
current_speed = 0.0
change_threshold = 100
target_speed = 0
current_speed = 0
user_mode = USER_MODES["MANUAL"]

motor_running = input_volt_check(motor_running)
update_direction_leds(0.0)

time.sleep(1.0) # delay for initialisation of io and user

command = 0.0
tilt = None                # degrees from upright (+ when angle > REF_ANGLE)
target_angle = 0.0         # degrees from upright, moved by dithering
error = 0.0
previous_error = 0.0
integral = 0.0
derivative = 0.0
p_term = 0.0
i_term = 0.0
d_term = 0.0

previous_ns = time.monotonic_ns()


while True:
    motor_running = input_volt_check(motor_running)

    mode_btn.update(gpio.check_control_switch())

    if mode_btn.check_state() == "released":
        user_mode = (user_mode + 1) % len(USER_MODES) # rotate through modes
        gpio.switch_led_on(user_mode % 2 == 1)

        # resetting everyting
        user_pot.reset()
        command = 0.0
        previous_error = 0.0
        previous_ns = time.monotonic()
        motor.stop()
        update_direction_leds(0.0)
        integral = 0.0
        derivative = 0.0
        error = 0.0
        p_term = 0.0
        i_term = 0.0
        d_term = 0.0


    if user_mode == USER_MODES["MANUAL"]:
        change = user_pot.get_pot_change()

        if change > change_threshold:
            target_speed = min((change * (pot_gain * imu.read_angle()) / pin_res) * 100, 100)
        
        elif change < -change_threshold:
            target_speed = max((change * (pot_gain * imu.read_angle()) / pin_res) * 100, -100)

        else:
            target_speed = 0

        if target_speed != 0:
            current_speed = target_speed

        elif current_speed > 0:
            current_speed -= speed_ramp_down
            current_speed = max(current_speed, 0)

        elif current_speed < 0:
            current_speed += speed_ramp_down
            current_speed = min(current_speed, 0)

        
        if current_speed != prev_speed:
            motor.set_speed(current_speed)
            prev_speed = current_speed

        time.sleep(0.02)


    elif user_mode == USER_MODES["PID"]:
        now_ns = time.monotonic_ns()
        dt = (now_ns - previous_ns) / 1e9
        previous_ns = now_ns

        angle = imu.read_angle()
        print(angle)

        if angle is None:
            tilt = None
            control_allowed = False

        else:
            tilt = wrap_angle(angle - REF_ANGLE)
            control_allowed = abs(tilt) <= ANGLE_LIMIT


        if control_allowed:

            error = tilt
           # print(error)
            if 0.0 < dt < 0.1:
                # Filtered derivative of the error.
                raw_derivative = (error - previous_error) / dt
                derivative += DERIV_FILTER * (raw_derivative - derivative)

                # Integral with anti-windup clamp.
                if KI > 0.0 and abs(error) > ANGLE_DEAD_BAND:
                    integral += error * dt
                    limit = INTEGRAL_LIMIT / KI
                    integral = clamp(integral, -limit, limit)

            p_term = KP * error
            i_term = KI * integral
            d_term = KD * derivative
           # print(p_term, i_term, d_term)
            if abs(error) <= ANGLE_DEAD_BAND:
                requested_command = 0.0
            else:
                requested_command = p_term + i_term + d_term

            if REVERSE_MOTOR:
                requested_command = -requested_command

            command = set_clamped_motor_speed(requested_command)

            update_direction_leds(command)

            previous_error = error


        else:
            motor.stop()
            update_direction_leds(0.0)

            command = 0.0
            integral = 0.0
            derivative = 0.0
            error = 0.0
            p_term = 0.0
            i_term = 0.0
            d_term = 0.0

        # Maintain the loop period.
        elapsed = (time.monotonic_ns() - now_ns) / 1e9
        remaining = LOOP_TIME - elapsed

        if remaining > 0:
            time.sleep(remaining)

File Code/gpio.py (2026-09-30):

import board
import digitalio
import analogio
import pwmio

PIN_RES = 65535
LED_FREQ = 100
PICO_VOLT_REF = 3.3

# using voltage divider to get low and high input voltage boundaries
H_BRIDGE_VL = 12 * 10 / 92
H_BRIDGE_VH = 13 * 10 / 92

# adc input voltage reading from voltage divider
ADC_VIN = analogio.AnalogIn(board.A1)

CONTROL_SW_PIN = digitalio.DigitalInOut(board.GP10)
CONTROL_SW_PIN.direction = digitalio.Direction.INPUT # already has pull up

SW_LED_PIN = digitalio.DigitalInOut(board.GP11)
SW_LED_PIN.direction = digitalio.Direction.OUTPUT
SW_LED_PIN.value = False

PWM_LED1 = pwmio.PWMOut(board.GP13, frequency=LED_FREQ, duty_cycle=0)
PWM_LED2 = pwmio.PWMOut(board.GP12, frequency=LED_FREQ, duty_cycle=0)


def set_control_led_brightness(led, pwm):
    pwm = int(min(abs(pwm), 100))
    if led == 1:
        PWM_LED1.duty_cycle = int(pwm * PIN_RES / 100)
    elif led == 2:
        PWM_LED2.duty_cycle = int(pwm * PIN_RES / 100)

def is_vin_correct():
    voltage = (ADC_VIN.value * PICO_VOLT_REF) / PIN_RES
    return (voltage >= H_BRIDGE_VL and voltage <= H_BRIDGE_VH)

def switch_led_on(on):
    SW_LED_PIN.value = on

def check_control_switch():
    return not CONTROL_SW_PIN.value # pin is pull up so switch off means HIGH

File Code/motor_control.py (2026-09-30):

import board
import digitalio
import pwmio
from gpio import PIN_RES

MOTOR_FREQ = 20000

MOTOR_SW_PIN = digitalio.DigitalInOut(board.GP17)
MOTOR_SW_PIN.direction = digitalio.Direction.OUTPUT
MOTOR_SW_PIN.value = False # have it off at the start

MOTOR_PWM1 = pwmio.PWMOut(board.GP20, frequency=MOTOR_FREQ, duty_cycle=0)
MOTOR_PWM2 = pwmio.PWMOut(board.GP21, frequency=MOTOR_FREQ, duty_cycle=0)


def stop():
    MOTOR_PWM1.duty_cycle = 0
    MOTOR_PWM2.duty_cycle = 0

def turn_on(on):
    stop()
    MOTOR_SW_PIN.value = on

def set_speed(speed):
    # if MOTOR_SW_PIN.value: # don't try if switch isn't closed
    speed = int(max(-100, min(100, speed)))
    #print(speed)
    if speed > 0:
        MOTOR_PWM2.duty_cycle = 0
        MOTOR_PWM1.duty_cycle = int(speed * PIN_RES / 100.0)

    elif speed < 0:
        MOTOR_PWM1.duty_cycle = 0
        MOTOR_PWM2.duty_cycle = int(abs(speed) * PIN_RES / 100.0)

    else:
        stop()

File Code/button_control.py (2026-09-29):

NUMBER_OF_POLLS = 4

class Button:

    def __init__(self, state=False, new_state_count=0):
        self.state = state
        self.new_state_count = new_state_count
        self.normal_state = self.state
        self.changed = False

    def update(self, new_state):
        if new_state != self.state:
            self.new_state_count += 1
            if self.new_state_count >= NUMBER_OF_POLLS:
                self.state = new_state
                self.changed = True
                self.new_state_count = 0
        else:
            self.new_state_count = 0

    def check_state(self):
        if self.changed:
            self.changed = False
            if self.state == self.normal_state:
                return "released"
            else:
                return "pushed"

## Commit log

2026-07-29 added folders for CAD design and schematics
2026-08-05 added voltage regulator for Raspberry Pi power
    [inverted_pendulum_shield.kicad_pcb, inverted_pendulum_shield.kicad_sch]
2026-08-05 added reverse polarity protection
    [inverted_pendulum_shield.kicad_sch]
2026-08-09 Added parts order and extra peripherals to shield
    [inverted_pendulum_shield.kicad_sch, parts_order.xlsx]
2026-08-09 Add all current CAD files
    [base.SLDPRT, bearing.SLDPRT, bearingcover.SLDPRT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]
2026-08-10 Add files via upload
    DC Motor PWM control template is complete
2026-08-10 Rename PWM Motor Control.py to Code/PWM Motor Control.py
2026-08-10 added the buck converters and H bridge
    [inverted_pendulum_shield.kicad_sch]
2026-08-10 Sort files into directories
    [Assem2.SLDASM, base.SLDPRT, bearing.SLDPRT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]
2026-08-11 Finished schematic and started on the footprints and parts list
    [inverted_pendulum_shield.kicad_sch, parts_order.xlsx]
2026-08-12 Finished schematic and completed ERC
    [inverted_pendulum_shield.kicad_pcb, inverted_pendulum_shield.kicad_sch, parts_order.xlsx]
2026-08-12 Made initial pcb layout without wiring
    [691137710002.stp, 691137710004.stp, Same_Sky_TB002-500-02BE.step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]
2026-08-12 Finished PCB
    [inverted_pendulum_shield.kicad_pcb, inverted_pendulum_shield.kicad_sch]
2026-08-16 Made next revision of schematic and with parts of pcb done
    [inverted_pendulum_shield.kicad_pcb, inverted_pendulum_shield.kicad_sch, parts_order.xlsx]
2026-08-16 finished revision 2 of pcb and schematics
    [inverted_pendulum_shield.kicad_pcb, inverted_pendulum_shield.kicad_sch, parts_order.xlsx]
2026-08-18 Meeting changes
    [inverted_pendulum_shield.kicad_pcb, inverted_pendulum_shield.kicad_sch]
2026-08-18 Finished BOM and finalised PCB layout
    [inverted_pendulum_shield.csv, inverted_pendulum_shield.kicad_pcb, inverted_pendulum_shield.kicad_sch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]
2026-08-19 Finished final schematic and PCB revisions
    [inverted_pendulum_shield.csv, inverted_pendulum_shield.kicad_pcb, inverted_pendulum_shield.kicad_sch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]
2026-08-19 Finished parts order and added DRC and ERC saves
    [inverted_pendulum_shield.csv, parts_order.xlsx]
2026-08-25 Add files via upload
    Code for imu to test if it's compatible with the imu (BNO055)
2026-08-26 added basic PID control system
2026-08-26 Update PID controller to use pitch instead of heading
2026-09-07 Marking off parts for order
    [inverted_pendulum_shield.csv, inverted_pendulum_shield.kicad_pcb, parts_order.xlsx]
2026-09-14 tested the PCB in full and created a gpio module with test code in main
2026-09-14 added git ignore file for kicad files
2026-09-16 update all files
    [arm1.2.SLDPRT, arms1.1.SLDASM, arms2.0.3MF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]
2026-09-16 Add all cad directories
    [arm1.2.SLDPRT, wheel1.2.SLDPRT]
2026-09-16 Deleted accidentally added temp cad files
2026-09-17 Added readme and pcb photo
    [691137710002.stp, 691137710004.stp, Same_Sky_TB002-500-02BE.step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]
2026-09-17 changed readme layout
    [inverted_pendulum_shield.kicad_sch]
2026-09-21 update the costs of the parts order to include gst
    [parts_order.xlsx]
2026-09-21 Add new pendulum version files and dimensions spreadsheet
    [Assem2.SLDASM, arm1.2.SLDPRT, pendulum1.0.SLDASM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]
2026-09-30 adding the PID stuff
2026-09-30 implemented bugged integral stuff
    [gpio.py, main.py, pot_test.py]
2026-09-30 Add pendulum1.3 and print files
    [arm1.2.3MF, arm1.2.SLDPRT, arm1.3.3MF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]
2026-09-30 tried to fix motor studder bug
    [main.py, motor_control.py]
2026-10-10 fixed a couple comment errors
